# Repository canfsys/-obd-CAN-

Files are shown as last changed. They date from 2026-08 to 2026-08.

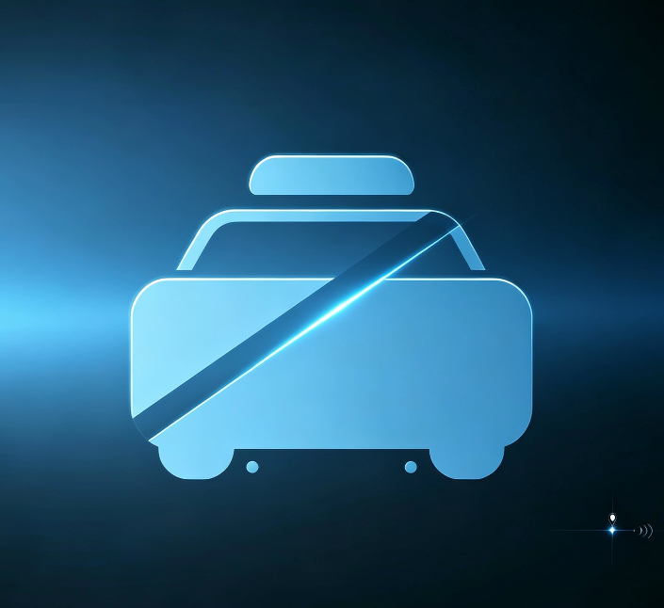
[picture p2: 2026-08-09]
miniprogram/miniprogram/images/car.png

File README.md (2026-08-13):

# OBD-CAN 车载终端 — 全链路开源项目

一套面向车联网场景的 **车载数据采集与远程监控系统**，从 PCB 硬件设计、CAN 总线数据采集、4G 上传、云端存储到微信小程序远程监控，全链路开源。

## 📦 仓库组成

| 目录 | 说明 | 核心技术 |
|---|---|---|
| [`esp32/`](esp32/README.md) | **ESP32-S3 车载终端固件** — 双通道 CAN 采集、GPS、SD 卡日志、低功耗电源管理 | C / ESP-IDF v5.3.1 / FreeRTOS |
| [`miniprogram/`](miniprogram/README.md) | **微信小程序** — 实时位置、轨迹回放、CAN 状态、历史图表、告警推送 | 微信云开发 / 云函数 |
| [`iot/`](iot/README.md) | **4G 物联网模块（银尔达 M100PG-DTU 固件版）** — 串口桥接脚本，HTTP 上报 + MQTT 下行指令 | Lua（银尔达平台） |
| [`hardware/`](hardware/README.md) | **PCB 硬件设计** — ESP32-S3 四层板（双 CAN、SD、4G、GPS、电源管理） | 嘉立创EDA专业版 / CERN-OHL-S-2.0 |

## 🏗️ 系统架构

```mermaid
graph TD
    HW["PCB 硬件设计<br/>(hardware/)"] -->|驱动| FW["ESP32-S3 车载终端固件<br/>(esp32/)"]
    FW <-->|"UART 串口协议"| IOT["4G 物联网模块<br/>(iot/) 银尔达 M100PG-DTU"]
    IOT -->|"HTTP POST (4G网络)"| CLOUD["云函数 upload<br/>(云数据库存储)"]
    CLOUD <-->|"轮询 15 秒"| MP["微信小程序<br/>(miniprogram/)"]
    CLOUD -->|"定时检测"| AC["alertChecker"]
    AC --> NT["notify"]
    NT -->|"微信订阅消息推送"| MSG["车辆告警通知"]
```

**数据链路**：车辆 CAN 数据 → ESP32 解析 → 4G 模块 HTTP 上报 → 腾讯云开发数据库 → 小程序 15 秒轮询展示 → 异常离线/非法移动 → 微信订阅消息告警。

## 🚀 快速开始

```bash
# ESP32 固件（见 esp32/README.md）
cd esp32
idf.py set-target esp32s3
idf.py build && idf.py -p COM17 flash

# 小程序：微信开发者工具导入本仓库根目录，按 miniprogram/README.md 部署
# 4G 模块：银尔达平台上传 iot/espBridge.lua，按 iot/config.md 配置通道
```

## 📄 文档索引

| 文档 | 内容 |
|---|---|
| [esp32/PROJECT_SUMMARY.md](esp32/PROJECT_SUMMARY.md) | 硬件连接、多任务架构、踩坑记录、版本记录 |
| [esp32/WAKEUP_CONFIG_SUMMARY.md](esp32/WAKEUP_CONFIG_SUMMARY.md) | 电源管理 / 唤醒配置详解 |
| [hardware/README.md](hardware/README.md) | PCB 硬件设计、引脚定义、打样/贴片说明 |
| [miniprogram/DATA_DOC.md](miniprogram/DATA_DOC.md) | 数据字段定义、数据库集合、告警链路、云函数部署 |
| [iot/config.md](iot/config.md) | 4G 平台网络通道配置 |

## ⚠️ 部署须知

- 仓库中小程序端配置已**脱敏**（`YOUR_APPID`、`YOUR_ENV_ID`、`YOUR_TEMPLATE_ID` 等占位符），部署前需替换为自己的配置，详见 `miniprogram/README.md`
- ESP32 需使用 N8R2 模组（8MB Flash + 2MB PSRAM，Quad SPI），详见 `esp32/README.md`

## 📜 许可证

本项目基于 [GPL-3.0](LICENSE) 许可证开源。

> ⚠️ **免责声明**：本项目为个人开发的参考实现，硬件涉及 CAN 总线通信与车辆数据，实际部署前请充分测试并评估安全性。

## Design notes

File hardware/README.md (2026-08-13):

# OBD-CAN 车载终端 — 硬件设计

> **硬件许可证：** [CERN-OHL-S-2.0](LICENSE)（强 copyleft，衍生硬件必须同样开源）
> **EDA 工具：** 嘉立创EDA专业版（LCEDA Pro）
> **状态：** PCB 已设计完成，尚未量产

## 📋 技术规格

| 项目 | 规格 |
|---|---|
| 主控 | ESP32-S3-WROOM-1-N8R2（8MB Flash / 2MB PSRAM，Quad SPI） |
| CAN1 | ESP32-S3 内置 TWAI 控制器 + SIT1145AQ 收发器（1MHz） |
| CAN2 | MCP2515 外置 CAN 控制器（SPI 8MHz）+ SIT1145AQ 收发器 |
| 供电 | 车载 12V 输入，含 3.8V_EN 电源控制 |
| 存储 | MicroSD 卡（SDMMC 4-bit 模式，独立电源使能） |
| 通信 | 4G 模块 UART1、GPS 模块 UART1（复用）、DS18B20 单总线 |
| 检测 | 电池电压 ADC（2:1 分压）+ 测量使能 |
| 电源管理 | Light sleep / Deep sleep，GPIO1 EXT1 高电平唤醒 |
| 板层 | 4 层板（含内层 G1/G2） |

## 📁 目录结构

```
hardware/
├── LICENSE                        # CERN-OHL-S-2.0 硬件开源许可证
├── schematic.pdf                  # 原理图（PDF 通用格式）
├── gerber/
│   ├── Gerber_PCB1.zip            # 完整 Gerber 打包（可直接打样）
│   ├── Gerber_TopLayer.GTL        # 顶层铜箔
│   ├── Gerber_BottomLayer.GBL     # 底层铜箔
│   ├── Gerber_InnerLayer1.G1      # 内层1
│   ├── Gerber_InnerLayer2.G2      # 内层2
│   ├── Gerber_*SilkscreenLayer    # 丝印层（顶/底）
│   ├── Gerber_*SolderMaskLayer    # 阻焊层（顶/底）
│   ├── Gerber_*PasteMaskLayer     # 锡膏层（顶/底）
│   ├── Gerber_BoardOutlineLayer.GKO  # 板框
│   ├── Drill_PTH/NPTH/Via.DRL     # 钻孔文件
│   ├── FlyingProbeTesting.json    # 飞针测试文件
│   └── PCB下单必读.txt
├── bom/
│   ├── BOM_Board1_PCB1.xlsx       # 物料清单（元器件/数量/封装）
│   └── PickAndPlace_PCB1.xlsx     # 贴片坐标文件（SMT 使用）
├── images/
│   ├── 3D_PCB1_TopLayer.png       # PCB 3D 顶面预览
│   └── 3D_PCB1_BottomLayer.png    # PCB 3D 底面预览
└── source/
    └── OBD_CAN_Module_v2.0.eprj2  # 嘉立创EDA专业版工程源文件（可二次编辑）
```

## 🔌 引脚分配

| 功能 | 组件 | GPIO | 说明 |
|---|---|:----:|---|
| UART0_TX / UART0_RX | 调试串口 | 43 / 44 | 控制台输出 (115200) |
| USB D- / D+ | 内置 | 19 / 20 | USB Serial/JTAG 烧录 |
| SPI_MISO / MOSI / SCK | spi_bus | 16 / 17 / 18 | 共享 SPI2 总线 |
| SIT1145-1_CS | sit1145 (CAN1) | 5 | TWAI 路收发器 (1MHz, mode1) |
| SIT1145-2_CS | sit1145 (CAN2) | 6 | MCP2515 路收发器 (1MHz, mode1) |
| MCP2515_CS | mcp2515 | 7 | 外置 CAN 控制器 (8MHz, mode0) |
| MCP2515_INT | mcp2515 | 8 | 中断引脚 (下降沿) |
| TWAI_TX / TWAI_RX | twai | 10 / 9 | ESP32-S3 内置 CAN |
| SD_CLK/CMD/D0~D3 | sd_card | 14/15/2/4/12/13 | SDMMC 4-bit |
| SD_PWR_EN | sd_card | 38 | SD 卡电源使能 |
| 4G_TX / 4G_RX | modem_4g | 41 / 42 | 4G 模块 UART1 |
| 4G_RESET | modem_4g | 47 | 4G 模块复位 |
| 3.8V_EN | 电源控制 | 21 | 4G 模块/外部电源使能 |
| BAT_ADC | adc | 11 | 电池电压检测 (ADC2_CH0) |
| BAT_MEAS_EN | adc | 39 | ADC 通道开关 |
| DS18B20 | ds18b20 | 40 | 单总线温度传感器 |
| WAKE_IN | 外部中断 | 1 | GPIO1 EXT1 高电平唤醒 |

## 🛠️ 使用说明

### 打样 PCB
1. 将 `gerber/Gerber_PCB1.zip` 直接上传至嘉立创下单助手 / 制板厂
2. 按 `PCB下单必读.txt` 中的要求下单

### 贴片生产（SMT）
1. 打开 `bom/BOM_Board1_PCB1.xlsx` 核对元器件
2. 使用 `bom/PickAndPlace_PCB1.xlsx` 贴片坐标文件
3. 配合飞针测试文件 `FlyingProbeTesting.json` 验证

### 二次开发（修改电路）
1. 用嘉立创EDA专业版打开 `source/OBD_CAN_Module_v2.0.eprj2` 工程文件
2. 修改后导出新的 Gerber / BOM / 原理图 PDF 更新到对应目录

## 📜 许可证

硬件设计基于 [CERN-OHL-S-2.0](LICENSE) 开源。固件与软件部分见仓库根目录 GPL-3.0 许可证。

> ⚠️ **免责声明**：本设计为个人开发参考，涉及车辆 CAN 总线与电气系统，实际使用前请充分测试并评估安全风险。

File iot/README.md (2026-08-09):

# IoT 物联网模块 — 4G 通信桥

> **模块型号：银尔达 M100PG-DTU 固件版**

本目录是车载终端 **4G 通信模块**（银尔达 M100PG-DTU）的桥接代码（银尔达物联网平台 Lua 任务），负责将 ESP32 采集到的车辆数据通过移动网络上报到云端，并接收云端下行的指令。

## 系统位置

```
┌──────────────┐   UART   ┌───────────────────────┐   HTTP/MQTT   ┌─────────────────┐
│   ESP32 固件  │◀────────▶│ 4G 模块 (espBridge.lua) │──────────────▶│ 云函数 upload   │
│ (esp32/)     │  串口协议 │ (本目录 iot/)           │   4G 网络      │ (miniprogram/)  │
└──────────────┘          └───────────────────────┘               └────────┬────────┘
                                                                           │
                                                                   ┌───────▼────────┐
                                                                   │ 微信小程序前端   │
                                                                   └────────────────┘
```

## 功能

- **UART 通信**：与 ESP32 交互，处理查询命令 `NET?` / `IMEI?` / `TIME?` / `GPS?` / `STATUS?`，返回 `KEY=VALUE` 格式数据
- **HTTP 上报**：将车辆实时状态 POST 到云端云函数 `/upload`（腾讯云开发环境）
- **MQTT 通道**：订阅 `carXXXdown` / 发布 `carXXXup` 主题，支持远程指令下行
- **GPS 透传**：模块自带 GPS 引擎，可向 ESP32 提供定位数据
- **网络透传**：4G 网络收到的数据透明转发给 ESP32

## 文件说明

| 文件 | 说明 |
|---|---|
| `espBridge.lua` | 银尔达平台 Lua 任务脚本（核心桥接逻辑） |
| `config.md` | 银尔达平台「网络通道」配置说明（HTTP/MQTT） |

## 使用前提

1. 一台 **银尔达 M100PG-DTU 固件版** 4G 模组（或兼容银尔达 Lua 平台的同系列模组）
2. 按 `config.md` 在平台控制台配置好网络通道
3. 将 `espBridge.lua` 上传为平台任务并启用

> 串口命令协议与 ESP32 侧 `gps_poller` / `modem_4g` 组件对应，见 `esp32/PROJECT_SUMMARY.md`。

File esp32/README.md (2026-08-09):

# ESP32-S3 车载终端 — 多通道 CAN 数据采集

基于 **ESP32-S3-WROOM-1-N8R2** 的多通道 CAN 总线数据采集与存储终端，面向车载环境设计。支持内置 TWAI 控制器 + 外置 MCP2515 双通道 CAN 采集、SD 卡 CSV 日志、GPS 定时轮询、电池电压监测，以及完整的 light/deep sleep 低功耗电源管理。

## 功能特性

- 🚗 **双通道 CAN 采集**
  - CAN1: ESP32-S3 内置 TWAI 控制器 (125kbps) + SIT1145 收发器
  - CAN2: MCP2515 外置控制器 (SPI) + SIT1145 收发器
- 📦 **PSRAM 双缓冲区** — 4×64KB 缓冲区，CAN 帧满后通过共享信号量异步落盘，不丢帧
- 💾 **SD 卡 CSV 日志** — 按组件自动建目录、文件自动编号 (can_0001.csv) 并追加写入
- 🔋 **三级电源管理** — NORMAL → STANDBY → SLEEP (light sleep 3 次定时器唤醒后转 deep sleep)
- 🛰️ **GPS 定时轮询** — 进入 sleep 前设置 3 分钟定时器，唤醒后通过 UART1 查询 GPS 状态
- 📡 **4G 模块接口** — UART1 私有协议 + 复位控制 (开发中)
- 🌡️ **温度/电压监测** — DS18B20 单总线温度 + ADC 电池电压检测
- ⚡ **多核任务架构** — CAN 接收任务绑核最高优先级，SD 写入任务最低优先级防阻塞
- 🔋 **低功耗唤醒** — GPIO1 EXT1 高电平唤醒 + RTC 定时器自主唤醒

## 硬件要求

| 项目 | 规格 |
|---|---|
| 主控 | ESP32-S3-WROOM-1-N8R2 (8MB Flash / 2MB PSRAM) |
| CAN1 | ESP TWAI (GPIO9/10) + SIT1145AQ 收发器 (SPI 配置) |
| CAN2 | MCP2515 (SPI) + SIT1145AQ 收发器 |
| 存储 | MicroSD 卡 (SDMMC 4-bit 模式) |
| 外设 | 4G 模块 (UART1)、GPS 模块 (UART1)、DS18B20、电池 |

## 引脚分配

| 功能 | GPIO | 说明 |
|---|:----:|---|
| UART0_TX / UART0_RX | 43 / 44 | 调试串口 (115200) |
| USB D- / D+ | 19 / 20 | USB Serial/JTAG 烧录 |
| SPI_MISO / MOSI / SCK | 16 / 17 / 18 | 共享 SPI2 总线 |
| SIT1145-1_CS | 5 | CAN1 收发器配置 (1MHz, mode1) |
| SIT1145-2_CS | 6 | CAN2 收发器配置 (1MHz, mode1) |
| MCP2515_CS | 7 | 外置 CAN 控制器 (8MHz, mode0) |
| MCP2515_INT | 8 | 中断 (下降沿) |
| TWAI_TX / TWAI_RX | 10 / 9 | 内置 CAN 控制器 |
| SD_CLK/CMD/D0~D3 | 14/15/2/4/12/13 | SDMMC 4-bit |
| SD_PWR_EN | 38 | SD 卡电源使能 |
| 4G_TX / 4G_RX | 41 / 42 | 4G 模块 UART1 |
| 4G_RESET | 47 | 4G 模块复位 |
| 3.8V_EN | 21 | 4G 模块/外部电源使能 |
| BAT_ADC / BAT_MEAS_EN | 11 / 39 | 电池电压检测 |
| DS18B20 | 40 | 温度传感器 |
| WAKE_IN | 1 | GPIO1 EXT1 高电平唤醒 |

## 软件要求

- **ESP-IDF v5.3.1**（其他 v5.x 版本理论上兼容）
- 目标芯片: `esp32s3`
- 需启用 PSRAM（Quad SPI 模式，`CONFIG_SPIRAM_MODE_QUAD`）

## 构建与烧录

```bash
# 设置 ESP-IDF 环境后
idf.py set-target esp32s3
idf.py menuconfig    # 按需调整 (见下方注意事项)
idf.py build
idf.py -p COM17 flash   # 替换为你的串口号
idf.py monitor          # 或使用串口助手连接 UART0 (115200-8N1)
```

### ⚠️ 构建注意事项

1. **PSRAM 必须为 Quad SPI 模式**（N8R2 模组），否则启动报错
2. **Flash 大小需设为 8MB**（`idf.py menuconfig` → Serial flasher config）
3. 调试串口为 **UART0 (GPIO43/44)**，USB Serial/JTAG 仅用于烧录

## 项目结构

```
├── CMakeLists.txt              # EXTRA_COMPONENT_DIRS=components
├── main/
│   └── main.c                  # 主入口: 唤醒判断 + 初始化 + 4 任务
└── components/                 # 自定义组件 (14 个)
    ├── board_config/           # 板级引脚定义
    ├── spi_bus/                # SPI2_HOST 共享总线 + 设备名映射
    ├── sit1145/                # SIT1145AQ CAN 收发器驱动
    ├── mcp2515/                # MCP2515 CAN 控制器驱动 (含重试)
    ├── twai/                   # ESP TWAI CAN 驱动封装 (Alert 中断)
    ├── sd_card/                # SD 卡 FATFS 挂载/读写
    ├── sd_logger/              # SD 卡 CSV 日志写入器
    ├── can_buffer/             # PSRAM 双缓冲区管理器
    ├── can_parser/             # CAN 数据帧解析器
    ├── modem_4g/               # 4G 模块 (UART + AT 命令)
    ├── ds18b20/                # 单总线温度传感器
    ├── adc/                    # 电池电压检测
    ├── power_manager/          # 电源管理 (三种模式 + GPIO 唤醒)
    └── gps_poller/             # GPS 轮询器
```

## 多任务架构

| 任务 | 绑核 | 优先级 | 触发方式 | 功能 |
|---|:----:|:---:|---|---|
| `mcp2515_task` | Core0 | 24 | GPIO 下降沿 ISR | SPI 读 MCP2515 → 缓冲区 + 解析 |
| `twai_task` | Core1 | 24 | TWAI Alert(RXI) 中断 | 读 TWAI RX FIFO → 缓冲区 + 解析 |
| `sd_write_task` | Core1 | 1 | 共享信号量 | 缓冲区满 → 写 SD 卡 CSV |
| `sensor_task` | Core1 | 5 | `vTaskDelay(1000)` | 温度/电压打印 + 电源空闲检测 |

## 相关文档

- [PROJECT_SUMMARY.md](PROJECT_SUMMARY.md) — 硬件连接、架构、踩坑记录、版本记录
- [WAKEUP_CONFIG_SUMMARY.md](WAKEUP_CONFIG_SUMMARY.md) — 电源管理 / 唤醒配置详细说明

## 许可证

本项目基于 [GPL-3.0](LICENSE) 许可证开源。

> ⚠️ **免责声明**: 本项目为个人开发的参考实现，硬件涉及 CAN 总线通信，实际部署前请充分测试并评估安全性。

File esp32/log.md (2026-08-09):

GPIO1唤醒
[06:39:26.528] I (71669) MAIN: ===== 空闲超时, 进入待机 =====
[06:39:26.528] I (71669) TWAI: 卸载 TWAI 驱动
[06:39:26.528] I (71669) SD_CARD: SD 卡已卸载
[06:39:26.528] I (71679) POWER_MGR: ===== light sleep =====
[06:39:26.528] I (71679) SPI_BUS: SIT1145-1 TX(16bit): 98 03 | (无RX)
[06:39:26.528] I (71689) POWER_MGR: SIT1145-1 写 0x4C = 0x03
[06:39:26.528] I (71689) SPI_BUS: SIT1145-1 TX(16bit): 40 01 | (无RX)
[06:39:26.528] I (71699) POWER_MGR: SIT1145-1 写 0x20 = 0x01
[06:39:26.528] I (71709) SPI_BUS: SIT1145-1 TX(16bit): 08 00 | (无RX)
[06:39:26.528] I (71709) POWER_MGR: SIT1145-1 写 0x04 = 0x00
[06:39:26.528] I (71719) SPI_BUS: SIT1145-1 TX(16bit): 46 01 | (无RX)
[06:39:26.528] I (71719) POWER_MGR: SIT1145-1 写 0x23 = 0x01
[06:39:26.528] I (71729) SPI_BUS: SIT1145-1 TX(16bit): C2 FF | (无RX)
[06:39:26.528] I (71729) POWER_MGR: SIT1145-1 写 0x61 = 0xFF
[06:39:26.528] I (71739) SPI_BUS: SIT1145-1 TX(16bit): C3 00 | RX: C3 00 
[06:39:26.528] I (71739) POWER_MGR:   回读 0x61=0x00
[06:39:26.528] I (71749) SPI_BUS: SIT1145-1 TX(16bit): C6 FF | (无RX)
[06:39:26.528] I (71749) POWER_MGR: SIT1145-1 写 0x63 = 0xFF
[06:39:26.528] I (71759) SPI_BUS: SIT1145-1 TX(16bit): C8 FF | (无RX)
[06:39:26.528] I (71769) POWER_MGR: SIT1145-1 写 0x64 = 0xFF
[06:39:26.528] I (71769) SPI_BUS: SIT1145-1 TX(16bit): C9 00 | RX: C9 00 
[06:39:26.528] I (71779) POWER_MGR:   回读 0x64=0x00
[06:39:26.528] I (71779) SPI_BUS: SIT1145-1 TX(16bit): 02 01 | (无RX)
[06:39:26.528] I (71789) POWER_MGR: SIT1145-1 写 0x01 = 0x01
[06:39:26.528] I (71789) SPI_BUS: SIT1145-2 TX(16bit): 98 03 | (无RX)
[06:39:26.528] I (71799) POWER_MGR: SIT1145-2 写 0x4C = 0x03
[06:39:26.528] I (71799) SPI_BUS: SIT1145-2 TX(16bit): 40 01 | (无RX)
[06:39:26.528] I (71809) POWER_MGR: SIT1145-2 写 0x20 = 0x01
[06:39:26.528] I (71809) SPI_BUS: SIT1145-2 TX(16bit): 08 00 | (无RX)
[06:39:26.528] I (71819) POWER_MGR: SIT1145-2 写 0x04 = 0x00
[06:39:26.528] I (71829) SPI_BUS: SIT1145-2 TX(16bit): 46 01 | (无RX)
[06:39:26.528] I (71829) POWER_MGR: SIT1145-2 写 0x23 = 0x01
[06:39:26.528] I (71839) SPI_BUS: SIT1145-2 TX(16bit): C2 FF | (无RX)
[06:39:26.528] I (71839) POWER_MGR: SIT1145-2 写 0x61 = 0xFF
[06:39:26.528] I (71849) SPI_BUS: SIT1145-2 TX(16bit): C3 00 | RX: C3 00 
[06:39:26.528] I (71849) POWER_MG
[06:39:26.725] R:   回读 0x61=0x00
[06:39:26.725] I (71859) SPI_BUS: SIT1145-2 TX(16bit): C6 FF | (无RX)
[06:39:26.725] I (71859) POWER_MGR: SIT1145-2 写 0x63 = 0xFF
[06:39:26.725] I (71869) SPI_BUS: SIT1145-2 TX(16bit): C8 FF | (无RX)
[06:39:26.725] I (71879) POWER_MGR: SIT1145-2 写 0x64 = 0xFF
[06:39:26.725] I (71879) SPI_BUS: SIT1145-2 TX(16bit): C9 00 | RX: C9 00 
[06:39:26.725] I (71889) POWER_MGR:   回读 0x64=0x00
[06:39:26.725] I (71889) SPI_BUS: SIT1145-2 TX(16bit): 02 01 | (无RX)
[06:39:26.725] I (71899) POWER_MGR: SIT1145-2 写 0x01 = 0x01
[06:39:26.725] I (71899) POWER_MGR: MCP2515: 清除 WAKIF
[06:39:26.725] I (71909) SPI_BUS: MCP2515 TX(32bit): 05 2C 40 00 | (无RX)
[06:39:26.725] I (71909) POWER_MGR: MCP2515: 使能 WAKIE
[06:39:26.725] I (71919) SPI_BUS: MCP2515 TX(32bit): 05 2B 40 40 | (无RX)
[06:39:26.725] I (71919) POWER_MGR: MCP2515: 休眠
[06:39:26.725] I (71929) SPI_BUS: MCP2515 TX(32bit): 05 0F E0 20 | (无RX)
[06:39:26.725] I (71929) POWER_MGR: SPI/CAN 休眠完成 (已清除初始化标
[06:39:31.231] 志)
[06:39:31.231] rtc_gpio_is_valid_gpio(GPIO1) = 1
[06:39:31.231] I (71949) POWER_MGR: 进入 light sleep (3min GPS, GPIO1/42 唤醒)
[06:39:31.231] I (71949) POWER_MGR: 唤醒 原因=3(EXT1(GPIO1))
[06:39:31.231] I (71969) MAIN: ===== 唤醒后重新初始化外设 =====
[06:39:31.231] I (71969) MAIN: [1/5] 重新添加 SPI 设备...
[06:39:31.231] I (71969) SPI_BUS: 删除 SPI 设备 (handle=0x0x3fca6e00)
[06:39:31.231] I (71979) gpio: GPIO[5]| InputEn: 0| OutputEn: 0| OpenDrain: 0| Pullup: 1| Pulldown: 0| Intr:0 
[06:39:31.231] I (71989) SPI_BUS: 删除 SPI 设备 (handle=0x0x3fca6fb0)
[06:39:31.231] I (71989) gpio: GPIO[6]| InputEn: 0| OutputEn: 0| OpenDrain: 0| Pullup: 1| Pulldown: 0| Intr:0 
[06:39:31.231] I (71999) SPI_BUS: 删除 SPI 设备 (handle=0x0x3fca7160)
[06:39:31.231] I (72009) gpio: GPIO[7]| InputEn: 0| OutputEn: 0| OpenDrain: 0| Pullup: 1| Pulldown: 0| Intr:0 
[06:39:31.231] I (72019) SPI_BUS: 设备 (CS=5) 添加成功, 速度=1000000Hz, mode=1
[06:39:31.231] I (72019) SPI_BUS: 设备 (CS=6) 添加成功, 速度=1000000Hz, mode=1
[06:39:31.231] I (72029) SPI_BUS: 设备 (CS=7) 添加成功, 速度=8000000Hz, mode=0
[06:39:31.231] I (72039) MAIN: [2/5] 初始化 SIT1145...
[06:39:31.231] I (72039) SIT1145: 初始化 SIT1145-1 (CS=GPIO5)
[06:39:31.231] I (72049) SPI_BUS: SIT1145-1 TX(16bit): 02 07 | (无RX)
[06:39:31.231] I (72059) SPI_BUS: SIT1145-1 TX(16bit): 56 03 | (无RX)
[06:39:31.231] I (72059) SIT1145: SIT1145-1 写入: reg[0x26]=0x02
[06:39:31.231] I (72069) SPI_BUS: SIT1145-1 TX(16bit): 4C 02 | (无RX)
[06:39:31.231] I (72069) SIT1145: SIT1145-1 写入: reg[0x20]=0x32
[06:39:31.231] I (72079) SPI_BUS: SIT1145-1 TX(16bit): 40 32 | (无RX)
[06:39:31.231] I (72079) SPI_BUS: SIT1145-1 TX(16bit): 4D 00 | RX: 4D 02 
[06:39:31.231] I (72089) SPI_BUS: SIT1145-1 TX(16bit): 41 00 | RX: 41 32 
[06:39:31.231] I (72099) SPI_BUS: SIT1145-1 TX(16bit): 45 00 | RX: 45 A0 
[06:39:31.231] I (72099) SIT1145: SIT1145-1 读回验证: reg[0x26]=0x02, reg[0x20]=0x32, reg[0x22]=0xA0
[06:39:31.231] I (72109) SIT1145: SIT1145-1 验证通过 ✓
[06:39:31.231] I (72119) SIT1145: SIT1145-1 初始化完成 (retry=0)
[06:39:31.231] I (72119) SIT1145: 初始化 SIT1145-2 (CS=GPIO6)
[06:39:31.231] I (72129) SPI_BUS: SIT1145-2 TX(16bit): 02 07 | (无RX)
[06:39:31.231] I (72129) SPI_BUS: SIT1145-2 TX(16bit): 56 03 | (无RX)
[06:39:31.231] I 
[06:39:31.429] (72139) SIT1145: SIT1145-2 写入: reg[0x26]=0x05
[06:39:31.429] I (72139) SPI_BUS: SIT1145-2 TX(16bit): 4C 05 | (无RX)
[06:39:31.429] I (72149) SIT1145: SIT1145-2 写入: reg[0x20]=0x32
[06:39:31.429] I (72159) SPI_BUS: SIT1145-2 TX(16bit): 40 32 | (无RX)
[06:39:31.429] I (72159) SPI_BUS: SIT1145-2 TX(16bit): 4D 00 | RX: 4D 05 
[06:39:31.429] I (72169) SPI_BUS: SIT1145-2 TX(16bit): 41 00 | RX: 41 32 
[06:39:31.429] I (72169) SPI_BUS: SIT1145-2 TX(16bit): 45 00 | RX: 45 A8 
[06:39:31.429] I (72179) SIT1145: SIT1145-2 读回验证: reg[0x26]=0x05, reg[0x20]=0x32, reg[0x22]=0xA8
[06:39:31.429] I (72189) SIT1145: SIT1145-2 验证通过 ✓
[06:39:31.429] I (72189) SIT1145: SIT1145-2 初始化完成 (retry=0)
[06:39:31.429] I (72199) MAIN: [3/5] 初始化 MCP2515...
[06:39:31.429] I (72209) MCP2515: MCP2515 初始化开始 (INT=GPIO8)
[06:39:31.429] I (72209) MCP2515: GPIO8 下降沿中断已安装
[06:39:31.429] I (72219) SPI_BUS: MCP2515 TX(8bit): C0 | (无RX)
[06:39:31.429] I (72229) MCP2515: 复位完成
[06:39:31.429] I (72229) SPI_BUS: MCP2515 TX(24bit): 02 2A 00 | (无RX)
[06:39:31.429] I (72229) SPI_BUS: MCP2515 TX(24bit): 02 29 90 | (无RX)
[06:39:31.429] I (72239) SPI_BUS: MCP2515 TX(24bit): 02 28 02 | (无RX)
[06:39:31.429] I (72239) MCP2515: 波特率配置完成 (CNF1=0x00, CNF2=0x90, CNF3=0x02)
[06:39:31.429] I (72249) SPI_BUS: MCP2515 TX(24bit): 02 60 60 | (无RX)
[06:39:31.429] I (72259) SPI_BUS: MCP2515 TX(24bit): 02 70 60 | (无RX)
[06:39:31.429] I (72259) MCP2515: 过滤器已关闭 (接收所有帧)
[06:39:31.429] I (72269) SPI_BUS: MCP2515 TX(24bit): 02 0C 00 | (无RX)
[06:39:31.429] I (72269) MCP2515: RXnBF 引脚中断已关闭
[06:39:31.429] I (72279) SPI_BUS: MCP2515 TX(24bit): 02 2B 03 | (无RX)
[06:39:31.429] I (72289) MCP2515: INT 引脚中断已开启 (RXB0IE + RXB1IE)
[06:39:31.429] I (72289) SPI_BUS: MCP2515 TX(24bit): 02 2C 00 | (无RX)
[06:39:31.429] I (72299) MCP2515: 中断标志已清除
[06:39:31.429] I (72299) SPI_BUS: MCP2515 TX(24bit): 02 0F 00 | (无RX)
[06:39:31.429] I (72309) SPI_BUS: MCP2515 TX(24bit): 03 0E 00 | RX: FF FF FF 
[06:39:31.429] I (72319) MCP2515: MCP2515 验证 (retry=0, CANSTAT=0xFF, OPMOD=7 异常)
[06:39:31.429] W (72319) MCP2515: OPMOD 异常, 复位重试...
[06:39:31.429] I (72329) SPI_BUS: MCP2515 TX(8bit): C0 | (无RX)
[06:39:31.429] I (72339) SPI_BUS: MCP2515 TX(24bit): 02 2A 00 | (无RX)
[06:39:31.429] I (72339) SPI_BUS: MCP2515 TX(24bit): 02 29 90 | (无RX)
[06:39:31.635] 
[06:39:31.635] I (72349) SPI_BUS: MCP2515 TX(24bit): 02 28 02 | (无RX)
[06:39:31.635] I (72349) SPI_BUS: MCP2515 TX(24bit): 02 60 60 | (无RX)
[06:39:31.635] I (72359) SPI_BUS: MCP2515 TX(24bit): 02 70 60 | (无RX)
[06:39:31.635] I (72359) SPI_BUS: MCP2515 TX(24bit): 02 0C 00 | (无RX)
[06:39:31.635] I (72369) SPI_BUS: MCP2515 TX(24bit): 02 2B 03 | (无RX)
[06:39:31.635] I (72379) SPI_BUS: MCP2515 TX(24bit): 02 2C 00 | (无RX)
[06:39:31.635] I (72379) SPI_BUS: MCP2515 TX(24bit): 02 0F 00 | (无RX)
[06:39:31.635] I (72389) MCP2515: 重试 1: 重新配置 CANCTRL=0x00
[06:39:31.635] I (72389) SPI_BUS: MCP2515 TX(24bit): 03 0E 00 | RX: FF FF 00 
[06:39:31.635] I (72399) MCP2515: MCP2515 验证 (retry=1, CANSTAT=0x00, OPMOD=0 Normal ✓)
[06:39:31.635] I (72409) MAIN: [4/5] 挂载 SD 卡...
[06:39:31.635] I (72409) gpio: GPIO[14]| InputEn: 0| OutputEn: 0| OpenDrain: 0| Pullup: 1| Pulldown: 0| Intr:0 
[06:39:31.635] I (72419) gpio: GPIO[15]| InputEn: 0| OutputEn: 0| OpenDrain: 0| Pullup: 1| Pulldown: 0| Intr:0 
[06:39:31.635] I (72429) gpio: GPIO[2]| InputEn: 0| OutputEn: 0| OpenDrain: 0| Pullup: 1| Pulldown: 0| Intr:0 
[06:39:31.635] I (72439) gpio: GPIO[4]| InputEn: 0| OutputEn: 0| OpenDrain: 0| Pullup: 1| Pulldown: 0| Intr:0 
[06:39:31.635] I (72449) gpio: GPIO[12]| InputEn: 0| OutputEn: 0| OpenDrain: 0| Pullup: 1| Pulldown: 0| Intr:0 
[06:39:31.635] I (72459) gpio: GPIO[13]| InputEn: 0| OutputEn: 0| OpenDrain: 0| Pullup: 1| Pulldown: 0| Intr:0 
[06:39:31.858] I (72579) gpio: GPIO[14]| InputEn: 0| OutputEn: 0| OpenDrain: 0| Pullup: 1| Pulldown: 0| Intr:0 
[06:39:31.858] I (72579) gpio: GPIO[15]| InputEn: 0| OutputEn: 0| OpenDrain: 0| Pullup: 1| Pulldown: 0| Intr:0 
[06:39:31.858] I (72589) gpio: GPIO[2]| InputEn: 0| OutputEn: 0| OpenDrain: 0| Pullup: 1| Pulldown: 0| Intr:0 
[06:39:31.858] I (72599) gpio: GPIO[4]| InputEn: 0| OutputEn: 0| OpenDrain: 0| Pullup: 1| Pulldown: 0| Intr:0 
[06:39:31.858] I (72609) gpio: GPIO[12]| InputEn: 0| OutputEn: 0| OpenDrain: 0| Pullup: 1| Pulldown: 0| Intr:0 
[06:39:31.858] I (72619) gpio: GPIO[13]| InputEn: 0| OutputEn: 1| OpenDrain: 0| Pullup: 0| Pulldown: 0| Intr:0 
[06:39:31.858] I (72659) gpio: GPIO[13]| InputEn: 0| OutputEn: 0| OpenDrain: 0| Pullup: 1| Pulldown: 0| Intr:0 
[06:39:31.858] Name: SD
[06:39:31.858] Type: SDHC/SDXC
[06:39:31.858] Speed: 20.00 MHz (limit: 20.00 MHz)
[06:39:31.858] Size: 29818MB
[06:39:31.858] CSD: ver=2, sector_size=512, capacity=61067264 read_bl_len=9
[06:39:31.858] SSR: bus_width=4
[06:39:31.858] I (72679) SD_CARD: SD 卡初始化成功
[06:39:33.532] I (74249) SD_LOG: sit1145: 新文件 /sdcard/sit1145/can_0322.csv 已创建 (编号=322)
[06:39:35.047] I (75769) SD_LOG: mcp2515: 新文件 /sdcard/mcp2515/can_0321.csv 已创建 (编号=321)
[06:39:35.047] I (75769) MAIN: [5/5] 注册句柄...
[06:39:35.047] I (75769) MCP2515: 已注册任务 (handle=0x0x3fca8768) 接收 MCP2515 中断通知
[06:39:35.047] I (75779) MAIN: ===== 外设重新初始化完成 =====
[06:39:35.362] Guru Meditation Error: Core  1 panic'ed (Interrupt wdt timeout on CPU1). 
[06:39:35.362] 
[06:39:35.362] Core  1 register dump:
[06:39:35.362] PC      : 0x4037a0fe  PS      : 0x00060834  A0      : 0x8037e55c  A1      : 0x3fca9220  
[06:39:35.362] A2      : 0x3c061330  A3      : 0xb33fffff  A4      : 0x0000abab  A5      : 0x00060a23  
[06:39:35.362] A6      : 0x00001b8a  A7      : 0x3fc9a740  A8      : 0x00000000  A9      : 0x00060823  
[06:39:35.362] A10     : 0x3c061330  A11     : 0x3fc9808c  A12     : 0x00000000  A13     : 0x4cc00001  
[06:39:35.362] A14     : 0x3c046b3f  A15     : 0x0000abab  SAR     : 0x0000000a  EXCCAUSE: 0x00000006  
[06:39:35.362] EXCVADDR: 0x00000000  LBEG    : 0x40056f5c  LEND    : 0x40056f72  LCOUNT  : 0x00000000  
[06:39:35.362] 

GPIO42唤醒
[06:38:05.131] I (65575) MAIN: ===== 空闲超时, 进入待机 =====
[06:38:05.131] I (65575) TWAI: 卸载 TWAI 驱动
[06:38:05.131] I (65575) SD_CARD: SD 卡已卸载
[06:38:05.131] I (65585) POWER_MGR: ===== light sleep =====
[06:38:05.131] I (65585) SPI_BUS: SIT1145-1 TX(16bit): 98 03 | (无RX)
[06:38:05.131] I (65595) POWER_MGR: SIT1145-1 写 0x4C = 0x03
[06:38:05.131] I (65595) SPI_BUS: SIT1145-1 TX(16bit): 40 01 | (无RX)
[06:38:05.131] I (65605) POWER_MGR: SIT1145-1 写 0x20 = 0x01
[06:38:05.131] I (65615) SPI_BUS: SIT1145-1 TX(16bit): 08 00 | (无RX)
[06:38:05.131] I (65615) POWER_MGR: SIT1145-1 写 0x04 = 0x00
[06:38:05.131] I (65625) SPI_BUS: SIT1145-1 TX(16bit): 46 01 | (无RX)
[06:38:05.131] I (65625) POWER_MGR: SIT1145-1 写 0x23 = 0x01
[06:38:05.131] I (65635) SPI_BUS: SIT1145-1 TX(16bit): C2 FF | (无RX)
[06:38:05.131] I (65635) POWER_MGR: SIT1145-1 写 0x61 = 0xFF
[06:38:05.131] I (65645) SPI_BUS: SIT1145-1 TX(16bit): C3 00 | RX: C3 00 
[06:38:05.131] I (65645) POWER_MGR:   回读 0x61=0x00
[06:38:05.131] I (65655) SPI_BUS: SIT1145-1 TX(16bit): C6 FF | (无RX)
[06:38:05.131] I (65655) POWER_MGR: SIT1145-1 写 0x63 = 0xFF
[06:38:05.131] I (65665) SPI_BUS: SIT1145-1 TX(16bit): C8 FF | (无RX)
[06:38:05.131] I (65675) POWER_MGR: SIT1145-1 写 0x64 = 0xFF
[06:38:05.131] I (65675) SPI_BUS: SIT1145-1 TX(16bit): C9 00 | RX: C9 00 
[06:38:05.131] I (65685) POWER_MGR:   回读 0x64=0x00
[06:38:05.131] I (65685) SPI_BUS: SIT1145-1 TX(16bit): 02 01 | (无RX)
[06:38:05.131] I (65695) POWER_MGR: SIT1145-1 写 0x01 = 0x01
[06:38:05.131] I (65695) SPI_BUS: SIT1145-2 TX(16bit): 98 03 | (无RX)
[06:38:05.131] I (65705) POWER_MGR: SIT1145-2 写 0x4C = 0x03
[06:38:05.131] I (65705) SPI_BUS: SIT1145-2 TX(16bit): 40 01 | (无RX)
[06:38:05.131] I (65715) POWER_MGR: SIT1145-2 写 0x20 = 0x01
[06:38:05.131] I (65715) SPI_BUS: SIT1145-2 TX(16bit): 08 00 | (无RX)
[06:38:05.131] I (65725) POWER_MGR: SIT1145-2 写 0x04 = 0x00
[06:38:05.131] I (65735) SPI_BUS: SIT1145-2 TX(16bit): 46 01 | (无RX)
[06:38:05.131] I (65735) POWER_MGR: SIT1145-2 写 0x23 = 0x01
[06:38:05.131] I (65745) SPI_BUS: SIT1145-2 TX(16bit): C2 FF | (无RX)
[06:38:05.131] I (65745) POWER_MGR: SIT1145-2 写 0x61 = 0xFF
[06:38:05.131] I (65755) SPI_BUS: SIT1145-2 TX(16bit): C3 00 | RX: C3 00 
[06:38:05.131] I (65755) POWER_MGR:   回读 0x61=0x00
[06:38:05.131] I (65765) SPI_BUS: SIT1145-2 TX(16bit): C6 FF | (无RX)
[06:38:05.131] I (65765) POWER_MGR: SIT1145-2 写 0x63 = 0xFF
[06:38:05.131] I (65775) SPI_BUS: SIT1145-2 TX
[06:38:05.346] (16bit): C8 FF | (无RX)
[06:38:05.346] I (65785) POWER_MGR: SIT1145-2 写 0x64 = 0xFF
[06:38:05.346] I (65785) SPI_BUS: SIT1145-2 TX(16bit): C9 00 | RX: C9 00 
[06:38:05.346] I (65795) POWER_MGR:   回读 0x64=0x00
[06:38:05.346] I (65795) SPI_BUS: SIT1145-2 TX(16bit): 02 01 | (无RX)
[06:38:05.346] I (65805) POWER_MGR: SIT1145-2 写 0x01 = 0x01
[06:38:05.346] I (65805) POWER_MGR: MCP2515: 清除 WAKIF
[06:38:05.346] I (65815) SPI_BUS: MCP2515 TX(32bit): 05 2C 40 00 | (无RX)
[06:38:05.346] I (65815) POWER_MGR: MCP2515: 使能 WAKIE
[06:38:05.346] I (65825) SPI_BUS: MCP2515 TX(32bit): 05 2B 40 40 | (无RX)
[06:38:05.346] I (65825) POWER_MGR: MCP2515: 休眠
[06:38:05.346] I (65835) SPI_BUS: MCP2515 TX(32bit): 05 0F E0 20 | (无RX)
[06:38:05.346] I (65835) POWER_MGR: SPI/CAN 休眠完成 (已清除初始化标
[06:38:10.770] 志)
[06:38:10.770] rtc_gpio_is_valid_gpio(GPIO1) = 1
[06:38:10.770] I (65855) POWER_MGR: 进入 light sleep (3min GPS, GPIO1/42 唤醒)
[06:38:10.770] I (65855) POWER_MGR: 唤醒 原因=7(IO MUX GPIO)
[06:38:10.770] I (65875) MAIN: ===== 唤醒后重新初始化外设 =====
[06:38:10.770] I (65875) MAIN: [1/5] 重新添加 SPI 设备...
[06:38:10.770] I (65875) SPI_BUS: 删除 SPI 设备 (handle=0x0x3fca6e00)
[06:38:10.770] I (65885) gpio: GPIO[5]| InputEn: 0| OutputEn: 0| OpenDrain: 0| Pullup: 1| Pulldown: 0| Intr:0 
[06:38:10.770] I (65895) SPI_BUS: 删除 SPI 设备 (handle=0x0x3fca6fb0)
[06:38:10.770] I (65895) gpio: GPIO[6]| InputEn: 0| OutputEn: 0| OpenDrain: 0| Pullup: 1| Pulldown: 0| Intr:0 
[06:38:10.770] I (65905) SPI_BUS: 删除 SPI 设备 (handle=0x0x3fca7160)
[06:38:10.770] I (65915) gpio: GPIO[7]| InputEn: 0| OutputEn: 0| OpenDrain: 0| Pullup: 1| Pulldown: 0| Intr:0 
[06:38:10.770] I (65925) SPI_BUS: 设备 (CS=5) 添加成功, 速度=1000000Hz, mode=1
[06:38:10.770] I (65925) SPI_BUS: 设备 (CS=6) 添加成功, 速度=1000000Hz, mode=1
[06:38:10.770] I (65935) SPI_BUS: 设备 (CS=7) 添加成功, 速度=8000000Hz, mode=0
[06:38:10.770] I (65945) MAIN: [2/5] 初始化 SIT1145...
[06:38:10.770] I (65945) SIT1145: 初始化 SIT1145-1 (CS=GPIO5)
[06:38:10.770] I (65955) SPI_BUS: SIT1145-1 TX(16bit): 02 07 | (无RX)
[06:38:10.770] I (65965) SPI_BUS: SIT1145-1 TX(16bit): 56 03 | (无RX)
[06:38:10.770] I (65965) SIT1145: SIT1145-1 写入: reg[0x26]=0x02
[06:38:10.770] I (65975) SPI_BUS: SIT1145-1 TX(16bit): 4C 02 | (无RX)
[06:38:10.770] I (65975) SIT1145: SIT1145-1 写入: reg[0x20]=0x32
[06:38:10.770] I (65985) SPI_BUS: SIT1145-1 TX(16bit): 40 32 | (无RX)
[06:38:10.770] I (65985) SPI_BUS: SIT1145-1 TX(16bit): 4D 00 | RX: 4D 02 
[06:38:10.770] I (65995) SPI_BUS: SIT1145-1 TX(16bit): 41 00 | RX: 41 32 
[06:38:10.770] I (66005) SPI_BUS: SIT1145-1 TX(16bit): 45 00 | RX: 45 A8 
[06:38:10.770] I (66005) SIT1145: SIT1145-1 读回验证: reg[0x26]=0x02, reg[0x20]=0x32, reg[0x22]=0xA8
[06:38:10.770] I (66015) SIT1145: SIT1145-1 验证通过 ✓
[06:38:10.770] I (66025) SIT1145: SIT1145-1 初始化完成 (retry=0)
[06:38:10.770] I (66025) SIT1145: 初始化 SIT1145-2 (CS=GPIO6)
[06:38:10.770] I (66035) SPI_BUS: SIT1145-2 TX(16bit): 02 07 | (无RX)
[06:38:10.770] I (66035) SPI_BUS: SIT1145-2 TX(16bit): 56 03 | (无RX)
[06:38:10.770] I (66045) SIT1145: SIT1145-2 写入: reg[0x26]=0x05
[06:38:10.770] I (66045) SPI_BUS: SIT1145-2 TX(16bit): 4C 05 | (无RX)
[06:38:10.770] I (66055) SIT1145: SIT1145-2 写入: reg[0x20]=0x32
[06:38:10.770] I (66065) SPI_BUS: SIT1145-2 T
[06:38:10.987] X(16bit): 40 32 | (无RX)
[06:38:10.987] I (66065) SPI_BUS: SIT1145-2 TX(16bit): 4D 00 | RX: 4D 05 
[06:38:10.987] I (66075) SPI_BUS: SIT1145-2 TX(16bit): 41 00 | RX: 41 32 
[06:38:10.987] I (66075) SPI_BUS: SIT1145-2 TX(16bit): 45 00 | RX: 45 A8 
[06:38:10.987] I (66085) SIT1145: SIT1145-2 读回验证: reg[0x26]=0x05, reg[0x20]=0x32, reg[0x22]=0xA8
[06:38:10.987] I (66095) SIT1145: SIT1145-2 验证通过 ✓
[06:38:10.987] I (66095) SIT1145: SIT1145-2 初始化完成 (retry=0)
[06:38:10.987] I (66105) MAIN: [3/5] 初始化 MCP2515...
[06:38:10.987] I (66115) MCP2515: MCP2515 初始化开始 (INT=GPIO8)
[06:38:10.987] I (66115) MCP2515: GPIO8 下降沿中断已安装
[06:38:10.987] I (66125) SPI_BUS: MCP2515 TX(8bit): C0 | (无RX)
[06:38:10.987] I (66135) MCP2515: 复位完成
[06:38:10.987] I (66135) SPI_BUS: MCP2515 TX(24bit): 02 2A 00 | (无RX)
[06:38:10.987] I (66135) SPI_BUS: MCP2515 TX(24bit): 02 29 90 | (无RX)
[06:38:10.987] I (66145) SPI_BUS: MCP2515 TX(24bit): 02 28 02 | (无RX)
[06:38:10.987] I (66145) MCP2515: 波特率配置完成 (CNF1=0x00, CNF2=0x90, CNF3=0x02)
[06:38:10.987] I (66155) SPI_BUS: MCP2515 TX(24bit): 02 60 60 | (无RX)
[06:38:10.987] I (66165) SPI_BUS: MCP2515 TX(24bit): 02 70 60 | (无RX)
[06:38:10.987] I (66165) MCP2515: 过滤器已关闭 (接收所有帧)
[06:38:10.987] I (66175) SPI_BUS: MCP2515 TX(24bit): 02 0C 00 | (无RX)
[06:38:10.987] I (66175) MCP2515: RXnBF 引脚中断已关闭
[06:38:10.987] I (66185) SPI_BUS: MCP2515 TX(24bit): 02 2B 03 | (无RX)
[06:38:10.987] I (66195) MCP2515: INT 引脚中断已开启 (RXB0IE + RXB1IE)
[06:38:10.987] I (66195) SPI_BUS: MCP2515 TX(24bit): 02 2C 00 | (无RX)
[06:38:10.987] I (66205) MCP2515: 中断标志已清除
[06:38:10.987] I (66205) SPI_BUS: MCP2515 TX(24bit): 02 0F 00 | (无RX)
[06:38:10.987] I (66215) SPI_BUS: MCP2515 TX(24bit): 03 0E 00 | RX: FF FF 00 
[06:38:10.987] I (66225) MCP2515: MCP2515 验证 (retry=0, CANSTAT=0x00, OPMOD=0 Normal ✓)
[06:38:10.987] I (66225) MAIN: [4/5] 挂载 SD 卡...
[06:38:10.987] I (66235) gpio: GPIO[14]| InputEn: 0| OutputEn: 0| OpenDrain: 0| Pullup: 1| Pulldown: 0| Intr:0 
[06:38:10.987] I (66245) gpio: GPIO[15]| InputEn: 0| OutputEn: 0| OpenDrain: 0| Pullup: 1| Pulldown: 0| Intr:0 
[06:38:10.987] I (66255) gpio: GPIO[2]| InputEn: 0| OutputEn: 0| OpenDrain: 0| Pullup: 1| Pulldown: 0| Intr:0 
[06:38:10.987] I (66265) gpio: GPIO[4]| InputEn: 0| OutputEn: 0| OpenDrain: 0| Pullup: 1| Pulldown: 0| Intr:0 
[06:38:10.987] I (66275) gpio: GPIO[12]| InputEn: 0| OutputEn: 0| OpenDrain: 0| Pullup: 1| Pulldown: 0| Intr:0 
[06:38:10.987] I (66275) gpio: GPIO[13]| InputEn: 0| 
[06:38:11.206] OutputEn: 0| OpenDrain: 0| Pullup: 1| Pulldown: 0| Intr:0 
[06:38:11.206] I (66395) gpio: GPIO[14]| InputEn: 0| OutputEn: 0| OpenDrain: 0| Pullup: 1| Pulldown: 0| Intr:0 
[06:38:11.206] I (66395) gpio: GPIO[15]| InputEn: 0| OutputEn: 0| OpenDrain: 0| Pullup: 1| Pulldown: 0| Intr:0 
[06:38:11.206] I (66405) gpio: GPIO[2]| InputEn: 0| OutputEn: 0| OpenDrain: 0| Pullup: 1| Pulldown: 0| Intr:0 
[06:38:11.206] I (66415) gpio: GPIO[4]| InputEn: 0| OutputEn: 0| OpenDrain: 0| Pullup: 1| Pulldown: 0| Intr:0 
[06:38:11.206] I (66425) gpio: GPIO[12]| InputEn: 0| OutputEn: 0| OpenDrain: 0| Pullup: 1| Pulldown: 0| Intr:0 
[06:38:11.206] I (66435) gpio: GPIO[13]| InputEn: 0| OutputEn: 1| OpenDrain: 0| Pullup: 0| Pulldown: 0| Intr:0 
[06:38:11.206] I (66475) gpio: GPIO[13]| InputEn: 0| OutputEn: 0| OpenDrain: 0| Pullup: 1| Pulldown: 0| Intr:0 
[06:38:11.206] Name: SD
[06:38:11.206] Type: SDHC/SDXC
[06:38:11.206] Speed: 20.00 MHz (limit: 20.00 MHz)
[06:38:11.206] Size: 29818MB
[06:38:11.206] CSD: ver=2, sector_size=512, capacity=61067264 read_bl_len=9
[06:38:11.206] SSR: bus_width=4
[06:38:11.206] I (66495) SD_CARD: SD 卡初始化成功
[06:38:12.903] I (67995) SD_LOG: sit1145: 新文件 /sdcard/sit1145/can_0320.csv 已创建 (编号=320)
[06:38:14.404] I (69495) SD_LOG: mcp2515: 新文件 /sdcard/mcp2515/can_0319.csv 已创建 (编号=319)
[06:38:14.404] I (69495) MAIN: [5/5] 注册句柄...
[06:38:14.404] I (69495) MCP2515: 已注册任务 (handle=0x0x3fca8768) 接收 MCP2515 中断通知
[06:38:14.404] I (69505) MAIN: ===== 外设重新初始化完成 =====
[06:38:14.721] Guru Meditation Error: Core  1 panic'ed (Interrupt wdt timeout on CPU1). 
[06:38:14.721] 
[06:38:14.721] Core  1 register dump:
[06:38:14.721] PC      : 0x4037a0f6  PS      : 0x00060834  A0      : 0x8037e55c  A1      : 0x3fca9220  
[06:38:14.721] A2      : 0x3c061330  A3      : 0xb33fffff  A4      : 0x0000abab  A5      : 0x00060a23  
[06:38:14.721] A6      : 0x00001946  A7      : 0x3fc9a740  A8      : 0x00000001  A9      : 0x00060823  
[06:38:14.721] A10     : 0x3c061330  A11     : 0x3fc9808c  A12     : 0x00000000  A13     : 0x4cc00001  
[06:38:14.721] A14     : 0x00000020  A15     : 0x0000abab  SAR     : 0x00000004  EXCCAUSE: 0x00000006  
[06:38:14.721] EXCVADDR: 0x00000000  LBEG    : 0x400556d5  LEND    : 0x400556e5  LCOUNT  : 0xfffffffe  
[06:38:14.721]

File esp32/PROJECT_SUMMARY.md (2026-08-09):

# ESP32-S3 车载终端工程 — 项目摘要

> **芯片型号:** ESP32-S3-WROOM-1-N8R2  
> **开发环境:** ESP-IDF v5.3.1  
> **目标平台:** ESP32-S3 (esp32s3)  
> **最后更新:** 2026-07-21

---

## 1. 硬件连接

### 1.1 调试串口
- **UART0 (GPIO43 TX, GPIO44 RX)**: 115200-8N1，所有调试信息输出
- **USB Serial/JTAG (GPIO19/20)**: 仅用于固件烧录

### 1.2 完整引脚分配

| 功能 | 组件 | GPIO | 说明 |
|---|---|:----:|---|
| **USB_D- / USB_D+** | 内置 | 19 / 20 | USB Serial/JTAG (烧录用) |
| **UART0_TX / UART0_RX** | 调试串口 | 43 / 44 | 控制台输出 (115200) |
| **SPI_MISO** | spi_bus | 16 | 共享 SPI 总线 |
| **SPI_MOSI** | spi_bus | 17 | |
| **SPI_SCK** | spi_bus | 18 | |
| **SIT1145-1_CS** | sit1145 (CAN1) | 5 | TWAI 路收发器 (1MHz, mode1) |
| **SIT1145-2_CS** | sit1145 (CAN2) | 6 | MCP2515 路收发器 (1MHz, mode1) |
| **MCP2515_CS** | mcp2515 | 7 | 外置 CAN 控制器 (8MHz, mode0) |
| **MCP2515_INT** | mcp2515 | 8 | 中断引脚 (下降沿触发) |
| **TWAI_TX** | twai | 10 | ESP32-S3 内置 CAN 控制器 TX |
| **TWAI_RX** | twai | 9 | ESP32-S3 内置 CAN 控制器 RX |
| **SD_CLK/CMD/D0/D1/D2/D3** | sd_card | 14/15/2/4/12/13 | SDMMC 4-bit 模式 |
| **SD_PWR_EN** | sd_card | 38 | SD 卡电源使能 |
| **4G_TX / 4G_RX** | modem_4g | 41 / 42 | 4G 模块 UART1 (私有协议) |
| **4G_RESET** | modem_4g | 47 | 4G 模块复位 |
| **3.8V_EN** | 电源控制 | 21 | 4G 模块/外部电源使能 |
| **BAT_ADC** | adc | 11 | 电池电压检测 (ADC2_CH0) |
| **BAT_MEAS_EN** | adc | 39 | ADC 通道开关 |
| **DS18B20** | ds18b20 | 40 | 单总线温度传感器 |
| **WAKE_IN** | 外部中断 | 1 | GPIO1 EXT1 高电平唤醒 |
| **USB_DN / USB_DP** | USB | 19 / 20 | 内置 USB Serial/JTAG |

---

## 2. CAN 通信架构

| CAN 总线 | 控制器 | 收发器 | 连接方式 |
|---|---|---|---|
| **CAN1** | ESP TWAI (内置) | SIT1145-1 (CS=GPIO5) | TWAI TX=GPIO10, RX=GPIO9 → SIT1145-1 |
| **CAN2** | MCP2515 (SPI, CS=GPIO7) | SIT1145-2 (CS=GPIO6) | MCP2515 → SIT1145-2 |

### SPI 总线共享设备 (SPI2_HOST)

| 设备 | CS | 速度 | SPI mode | 用途 |
|---|:--:|:----:|:---:|---|
| SIT1145-1 | GPIO5 | 1MHz | mode 1 | 配置 TWAI 路收发器 |
| SIT1145-2 | GPIO6 | 1MHz | mode 1 | 配置 MCP2515 路收发器 |
| MCP2515 | GPIO7 | 8MHz | mode 0 | CAN 控制器通信 |

> ESP-IDF 驱动会分别为每个设备独立管理时序，切换 CS 时自动切换时钟速度。

---

## 3. 多任务架构

### 3.1 任务分配

| 任务 | 绑核 | 优先级 | 触发方式 | 功能 |
|---|:----:|:---:|---|---|
| `mcp2515_task` | **Core0** | **最高 (24)** | GPIO 下降沿 ISR → Task Notification | SPI 读 MCP2515 → PSRAM 缓冲区 + 解析 |
| `twai_task` | **Core1** | **最高 (24)** | TWAI Alert(RXI) 硬件中断 | 读 TWAI RX FIFO → PSRAM 缓冲区 + 解析 |
| `sd_write_task` | Core1 | 最低 (1) | 共享计数信号量永久阻塞 | 缓冲区满 → 写入 SD 卡 CSV 文件 |
| `sensor_task` | Core1 | 5 | `vTaskDelay(1000)` | 温度/电压/状态打印 + 电源管理空闲检测 |

### 3.2 数据流

```
CAN 数据帧到达
    │
    ├→ mcp2515_task / twai_task 收到
    │   ├→ can_buffer_write_csv()      ← PSRAM 双缓冲区 (所有数据备份到 SD)
    │   └→ can_parser_process()        ← 解析关心 ID, 更新 g_state
    │
    └→ PSRAM 缓冲区满 (64KB)
        └→ 共享信号量通知 sd_write_task
            └→ 追加写入 SD 卡 CSV 文件
```

---

## 4. 工程结构 (组件化)

```
sample_project/
├── CMakeLists.txt                 # EXTRA_COMPONENT_DIRS=components
├── sdkconfig
├── components/                    # 自定义组件目录 (14 个)
│   ├── board_config/              # 板级引脚定义
│   ├── spi_bus/                   # SPI2_HOST 共享总线 + 设备名映射
│   ├── sit1145/                   # SIT1145AQ CAN 收发器驱动
│   ├── mcp2515/                   # MCP2515 CAN 控制器驱动 (含重试)
│   ├── twai/                      # ESP TWAI CAN 驱动封装 (125kbps, Alert)
│   ├── sd_card/                   # SD 卡 FATFS 挂载/读写
│   ├── sd_logger/                 # SD 卡 CSV 日志写入器 (自动编号+追加)
│   ├── can_buffer/                # PSRAM 双缓冲区管理器 (降级: 内部 RAM)
│   ├── can_parser/                # CAN 数据帧解析器 + GPS 状态变量
│   ├── modem_4g/                  # 4G 模块 (UART + AT 命令)
│   ├── ds18b20/                   # 单总线温度传感器
│   ├── adc/                       # 电池电压检测
│   ├── power_manager/             # 电源管理 (三种模式 + GPIO 唤醒)
│   └── gps_poller/                # GPS 轮询器 (UART1 收发 + KEY=VALUE 解析)
├── main/
│   ├── CMakeLists.txt
│   └── main.c                     # 主入口: 唤醒判断 + 初始化 + 4 任务
├── WAKEUP_CONFIG_SUMMARY.md
└── PROJECT_SUMMARY.md
```

---

## 5. 各组件 API 速览

### board_config
```c
#include "board_config.h"
// 引脚宏: PIN_SPI_MOSI, PIN_SIT1_CS, PIN_TWAI_TX, PIN_WAKE_IN, PIN_UART0_TX 等
```

### spi_bus
```c
spi_bus_init_board(mosi, miso, sck);                        // 初始化 SPI2_HOST
spi_bus_add_device_custom(cs, clock_hz, mode, &handle);     // 添加 SPI 设备
spi_bus_del_device(handle);                                  // 删除 SPI 设备 (light sleep 唤醒)
spi_bus_set_device_name(handle, "SIT1145-1");                // SPI 日志带设备名
spi_bus_write_reg(handle, addr, data);                      // 写 16-bit 寄存器
spi_bus_read_reg(handle, addr, &data);                      // 读 16-bit 寄存器
spi_bus_transfer(handle, tx, rx, bit_len);                  // 原始全双工传输 + HEX 日志
```

### sit1145
```c
sit1145_init(SIT1145_DEV_1, handle);           // 初始化 (写入0x26→0x20, 三寄存器验证)
sit1145_verify_chip_id(SIT1145_DEV_1);          // 验证芯片 ID (0x74)
sit1145_read_reg(dev, reg, &val);               // 读寄存器
sit1145_write_reg(dev, reg, data);              // 写寄存器 (地址编码: (reg<<1)|R/W)
```

### mcp2515
```c
mcp2515_init(handle, int_pin);                  // 初始化 (重试 5 次)
mcp2515_register_task(task_handle);             // 注册通知任务
mcp2515_send_frame(&frame);                     // 发送 (0x40 装载 + 0x81 快速发送)
mcp2515_receive_frame(&frame);                  // 接收 (0xB0→0x90→0x05)
mcp2515_has_interrupt();                        // 检查 INT 引脚电平
```

### twai
```c
twai_driver_init(TX_PIN, RX_PIN);               // 初始化 (125kbps, rx_queue=128)
twai_driver_start();                             // 启动 TWAI + Alert(RXI+DOI)
twai_driver_stop();                              // 停止
twai_driver_deinit();                            // 卸载驱动 (light sleep 进入前)
twai_driver_transmit(&frame, ms);                // 发送
twai_driver_receive(&frame, ms);                 // 接收 (带日志)
twai_driver_wait_rx(timeout_ms);                 // Alert 阻塞等待 RX 数据
```

### sd_card
```c
sd_card_init(pwr_en_pin);                       // 挂载 SD 卡
sd_card_deinit();                               // 卸载
sd_card_write_file(path, data, len);            // 写文件
sd_card_read_file(path, buf, size, &out);       // 读文件
```

### sd_logger
```c
sd_logger_init("sit1145");                      // 创建新文件 + CSV 头
sd_logger_write("mcp2515", data, len);          // 追加写入
// 目录: /sdcard/sit1145/can_0001.csv
// 格式: timestamp_ms,can_id,dlc,d0~d7,extended,rtr
```

### can_buffer
```c
can_buffer_init(&ctx, "mcp2515");               // 分配 2 缓冲区 (PSRAM 优先, 降级内部 RAM)
can_buffer_write_csv(&ctx, id, dlc, data, ...);  // 写 CSV 行
can_buffer_get_full(&ctx, &buf, &size);          // 获取满缓冲区
can_buffer_release_full(&ctx);                   // 释放满缓冲区
```

### can_parser
```c
can_parser_process(can_id, data, dlc);           // 解析 CAN 帧, 更新 g_state
// g_state 包含: lat/lng/speed/net/csq/fix/sat/hdop/altitude/height/gps_time
//               voltage/fuel/temperature/rpm/throttle/车门/车窗/手刹/点火 等
```

### modem_4g
```c
modem_4g_init(tx, rx, reset, baud);             // 初始化 UART1
modem_4g_send_at("AT\r\n", resp, size, ms);     // 发送 AT 命令
```

### gps_poller
```c
gps_poller_uart_init();                          // GPIO21=高, 初始化 UART1
gps_poller_run_cycle();                          // 发送 STATUS?, 解析 KEY=VALUE, FIX=1 发 JSON
gps_poller_uart_deinit();                        // 关闭 UART1, GPIO21=低
```

### power_manager
```c
power_manager_init();                            // 初始化为 NORMAL 模式
power_manager_tick(now_ms);                      // 每秒检查空闲超时 (1min)
power_manager_should_standby();                  // 是否应进入待机
power_manager_enter_standby();                   // 进入 light sleep (3min GPS)
power_manager_enter_sleep();                     // 进入 deep sleep (仅 GPIO1)
power_manager_is_auto_wake();                    // 是否为定时器自主唤醒
power_manager_set_mode(mode);                    // 设置电源模式
```

---

## 6. sdkconfig 关键配置

```c
// 控制台: UART0 (GPIO43/44)
CONFIG_ESP_CONSOLE_UART_DEFAULT=y
CONFIG_ESP_CONSOLE_UART_NUM=0

// Flash 8MB & PSRAM
CONFIG_ESPTOOLPY_FLASHSIZE_8MB=y
CONFIG_SPIRAM=y
CONFIG_SPIRAM_MODE_QUAD=y
CONFIG_SPIRAM_SPEED_40M=y

// CPU 主频
CONFIG_ESP_DEFAULT_CPU_FREQ_MHZ=160
```

---

## 7. 电源管理模式 (核心)

### 三种模式

| 模式 | 描述 | 触发条件 | 4G 电源 | GPIO1 | GPIO42 |
|---|---|---|:---:|:-----:|:---:|
| **NORMAL** | 全速运行 | 上电 / GPIO 唤醒 | 高 | 输入 | UART1 |
| **STANDBY** | Light sleep | 1min 无 CAN 报文 | 高 | EXT1 唤醒 | IO MUX 唤醒 |
| **SLEEP** | Deep sleep | 定时器唤醒 3 次 | 低 | EXT1 唤醒 | 高阻态 |

### Light sleep 流程

```
正常模式 → 1分钟无CAN → light sleep (3min)
  3min 到 → [定时器唤醒]
           → GPIO21=高 (保持)
           → 初始化 UART1
           → 发送 STATUS?
           → 解析 KEY=VALUE (FIX=1 → 更新 g_state + 发 JSON)
           → 2 分钟窗口结束
           → 回到 light sleep (s_wake_count++)
           → 3 次后进 deep sleep
```

### Deep sleep 流程

```
deep sleep → 3min 到 → 重启
           → GPIO21=高
           → GPS 轮询 2min
           → GPIO21=低
           → deep sleep (循环)
```

### 唤醒源

| 唤醒源 | 作用阶段 | 唤醒原因码 | 操作 |
|---|---|:---:|---|
| GPIO1 (EXT1) | Light/Deep sleep | 1 | 全初始化外设 |
| GPIO42 (IO MUX) | Light sleep only | 2 | 全初始化外设 |
| RTC 定时器 | Light sleep only | 4 | GPS 轮询 |

---

## 8. 初始化日志 (当前版本)

```
I (786) MAIN: 外部唤醒/上电: 全初始化
I (786) MAIN: ===== 全初始化 =====
I (846) SPI_BUS: 初始化 SPI2_HOST 总线: MOSI=17, MISO=16, SCK=18
I (846) SPI_BUS: 总线初始化成功
I (846) SPI_BUS: 设备 (CS=5) 添加成功, 速度=1000000Hz, mode=1
I (846) SPI_BUS: 设备 (CS=6) 添加成功, 速度=1000000Hz, mode=1
I (856) SPI_BUS: 设备 (CS=7) 添加成功, 速度=8000000Hz, mode=0
I (866) SIT1145: SIT1145-1 写入: reg[0x26]=0x02
I (876) SIT1145: SIT1145-1 写入: reg[0x20]=0x32
I (896) SIT1145: SIT1145-1 读回验证: reg[0x26]=0x02, reg[0x20]=0x32, reg[0x22]=0xA8
I (916) SIT1145: SIT1145-1 验证通过 ✓
I (926) SIT1145: SIT1145-2 写入: reg[0x26]=0x05
I (966) SIT1145: SIT1145-2 读回验证: reg[0x26]=0x05, reg[0x20]=0x32, reg[0x22]=0xA8
I (1006) SIT1145: SIT1145-2 验证通过 ✓
I (1026) SIT1145: SIT1145-1 Chip ID = 0x74 ✓
I (1036) SIT1145: SIT1145-2 Chip ID = 0x74 ✓
I (1226) MCP2515: MCP2515 验证 (retry=1, CANSTAT=0x00, OPMOD=0 Normal ✓)
I (1266) TWAI: TWAI 驱动安装成功 (125kbps)
I (1266) TWAI: TWAI 通信启动, Alert 已配置 (RXI + DOI)
I (1516) SD_CARD: SD 卡初始化成功
I (2886) MAIN: PSRAM: 2097152 bytes
I (2906) CAN_BUF: mcp2515: 双缓冲区初始化完成 (PSRAM, 2×65536 bytes)
I (3956) MAIN: ===== 全初始化完成 =====

--- 进入 light sleep 后 ---
I (64426) POWER_MGR: 进入 light sleep (3min GPS, GPIO1/42 唤醒)
I (64446) POWER_MGR: 唤醒 原因=4(RTC定时器)
I (64475) MAIN: 定时器唤醒 (wake_count=0/3)
I (64475) GPS_POLL: ===== GPS 轮询: UART1 初始化 =====
I (64585) GPS_POLL: --- 第 1 次 STATUS? (已用 0 秒) ---
```

---

## 9. PSRAM 缓冲区分配

| 缓冲区 | 大小 | 数量 | 总占用 | 分配位置 |
|---|:----:|:----:|:---:|---|
| MCP2515 双缓冲区 | 64KB | 2 | 128KB | PSRAM (降级: 16KB 内部 RAM) |
| TWAI 双缓冲区 | 64KB | 2 | 128KB | PSRAM (降级: 16KB 内部 RAM) |
| **合计** | | **4个** | **256KB** | `heap_caps_malloc(size, MALLOC_CAP_SPIRAM)` |

---

## 10. 版本变更记录

| 日期 | 变更 | 说明 |
|---|---|---|
| 2026-07-15 | 初始组件化 | 9 个组件, 单任务轮询 |
| 2026-07-15 | 多任务架构 | 4 任务 Core0+Core1, PSRAM 双缓冲区, SD CSV 日志 |
| 2026-07-18 | **电源管理** | power_manager 组件: 三种模式 |
| 2026-07-18 | GPIO 唤醒调试 | Light sleep 唤醒问题排查 |
| 2026-07-18 | RTC GPIO API | rtc_gpio_init + EXT1 + pd_config |
| 2026-07-18 | Deep sleep 唤醒 | deep sleep 能正常唤醒 |
| 2026-07-18 | UART0 调试串口 | 控制台从 USB_JTAG 切换到 UART0 |
| 2026-07-20 | **GPS 轮询** | gps_poller 组件 |
| 2026-07-20 | 唤醒类型判断 | RTC_DATA_ATTR 标志 + app_main 判断 |
| 2026-07-20 | MCP2515 重试 | 复位重试 5 次 |
| 2026-07-20 | Light sleep 唤醒修复 | 删除 GPIO42 IO MUX 冲突 |
| 2026-07-21 | **完整 sleep 循环** | light sleep 3min × 3 → deep sleep 3min GPS |
| 2026-07-21 | wake_count 简化 | 单个 RTC 变量控制 light→deep 切换 |
| 2026-07-21 | STATUS? 直发 | GPS 轮询不再等待 GPS=OK |
| 2026-07-21 | SPI 休眠标志 | s_periph_initialized 防止 GPS 轮询时误休眠 |
| 2026-07-21 | GPIO42 唤醒恢复 | IO MUX 高电平唤醒重新加入 |
| 2026-07-21 | GPS 超时修复 | uart_read_bytes 200ms→2000ms |

---

## 11. 踩坑记录

### 11.1 PSRAM 模式错误
- N8R2 模组 PSRAM 是 **Quad SPI** 模式, 非 Octal

### 11.2 SIT1145 地址编码
- R/W 位在 **LSB (bit0)**: `ADDR_W = (reg<<1)|0`, `ADDR_R = (reg<<1)|1`

### 11.3 SIT1145 SPI mode
- SIT1145 使用 **mode 1** (下降沿采样)

### 11.4 Light sleep 无法唤醒 (已解决)
- 原因: GPIO1 未配置 `rtc_gpio_` API + `esp_sleep_pd_config(RTC_PERIPH, ON)`
- 原因: ESP-IDF 默认 `sleep: Configure to isolate all GPIO pins`
- 解决: `rtc_gpio_init + gpio_sleep_sel_dis + EXT1 + pd_config`

### 11.5 IO MUX 与 EXT1 冲突 (已解决)
- 同时使用 `esp_sleep_enable_gpio_wakeup()` 和 `esp_sleep_enable_ext1_wakeup()` 导致立即唤醒
- 解决: 只能二选一，GPIO1 用 EXT1，GPIO42(非 RTC) 用 IO MUX

### 11.6 Deep sleep 5 分钟自动重启 (已解决)
- 原因: Light sleep 的定时器残留到 deep sleep
- 解决: `esp_sleep_disable_wakeup_source(ESP_SLEEP_WAKEUP_TIMER)`

### 11.7 Light sleep 唤醒后 SPI 冲突 (已解决)
- 原因: `spi_bus_init_board()` 重复调用
- 解决: wake_reinit 中跳过总线初始化, 删除旧设备再添加

### 11.8 GPS 轮询 UART 收不到数据 (已解决)
- 原因: `uart_read_bytes()` 每次轮询超时 200ms 太短, 模块首字节在 200ms 后才到达
- 解决: 超时改为 2000ms

---

## 12. 常用命令

```bash
# 编译
idf.py build

# 烧录 (USB 线, 替换为你的串口号)
idf.py -p COM17 flash

# 查看 UART0 调试输出 (USB 转串口模块接 GPIO43/44)
# 串口助手: COMxx 115200-8N1
```

---

## 13. TO-DO / 后续改进

- [x] 基础 CAN 收发 (MCP2515 + TWAI)
- [x] 多任务架构 (4 任务)
- [x] SD 卡 CSV 日志
- [x] 三种电源模式 (NORMAL / STANDBY / SLEEP)
- [x] GPIO1 EXT1 高电平唤醒
- [x] GPS 轮询 (每 3 分钟, STATUS? 查询)
- [x] Light→Deep sleep 切换 (3 次后)
- [x] Flash 大小 8MB 修正
- [ ] DS18B20 温度传感器 (待硬件连接后验证)
- [ ] CPU 主频提升到 240MHz
- [ ] 4G 模块 AT 命令通信完善
- [ ] 外部 RTC 时间同步 (用 GPS TIME 校准)
- [ ] WiFi/BLE 功能测试
- [ ] 解析串口数据逻辑优化

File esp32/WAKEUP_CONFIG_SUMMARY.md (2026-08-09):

# ESP32-S3 唤醒配置问题 — 待排查

## 硬件信息

| 项目 | 值 |
|---|-----|
| 芯片 | ESP32-S3-WROOM-1-N8R2 |
| 唤醒引脚 | GPIO1 (无外部上下拉电阻) |
| 唤醒信号 | 外部手动加 3.3V 脉冲电压 (秒级) |

## 目标行为

1. **正常模式** → 2 分钟无 CAN 报文 → **待机模式 (light sleep)**
2. **待机模式** → GPIO1 高电平脉冲 → 应唤醒回到正常模式
3. **待机模式** → 5 分钟定时器到期 → **休眠模式 (deep sleep)**
4. **休眠模式** → GPIO1 高电平脉冲 → 应唤醒重启芯片

## 当前现象

- 进入 light sleep / deep sleep 成功（终端有打印）
- GPIO1 加 3.3V 高电平脉冲后 **没有任何反应**（终端无打印）
- 说明 GPIO1 没有触发唤醒

## 代码片段

所有唤醒配置代码均在 `components/power_manager/power_manager.c` 中。

### ① 待机模式 (light sleep) — power_manager_enter_standby()

```c
/* ===== 进入 light sleep 前的唤醒配置 ===== */

/* GPIO1: 输入 + 内部下拉, EXT1 高电平唤醒 */
gpio_set_direction(GPIO_NUM_1, GPIO_MODE_INPUT);
gpio_set_pull_mode(GPIO_NUM_1, GPIO_PULLDOWN_ONLY);
esp_sleep_enable_ext1_wakeup(1ULL << GPIO_NUM_1, ESP_EXT1_WAKEUP_ANY_HIGH);

/* 5 分钟 RTC 定时器唤醒 */
esp_sleep_enable_timer_wakeup(SLEEP_TIMER_TIMEOUT_US);  // 5*60*1000000 = 300000000 us

/* 进入 light sleep */
ESP_LOGI(TAG, "进入 light sleep, 5 分钟定时器已设");
fflush(stdout);
esp_light_sleep_start();

/* ===== 唤醒后处理 ===== */
esp_sleep_wakeup_cause_t cause = esp_sleep_get_wakeup_cause();
ESP_LOGI(TAG, "从 light sleep 唤醒, 原因: %d", cause);

// 恢复 GPIO38/39 电源控制
// ...

if (cause == ESP_SLEEP_WAKEUP_TIMER) {
    // 5 分钟无唤醒 → 进入休眠模式 (deep sleep)
    power_manager_enter_sleep();
}

// GPIO 唤醒 → 回到正常模式
return ESP_OK;  // 返回后重新初始化外设
```

### ② 休眠模式 (deep sleep) — power_manager_enter_sleep()

```c
/* ===== 进入 deep sleep 前的唤醒配置 ===== */

/* GPIO1: 输入 + 内部下拉, EXT1 高电平唤醒 */
gpio_set_direction(GPIO_NUM_1, GPIO_MODE_INPUT);
gpio_set_pull_mode(GPIO_NUM_1, GPIO_PULLDOWN_ONLY);
esp_sleep_enable_ext1_wakeup(1ULL << GPIO_NUM_1, ESP_EXT1_WAKEUP_ANY_HIGH);

/* 进入 deep sleep (不返回) */
esp_deep_sleep_start();
```

### ③ 待机前关闭的 GPIO

```c
/* 关闭 SD 卡电源 */
gpio_set_level(PIN_SD_PWR_EN, 0);   // GPIO38
/* 关闭 ADC 测量 */
gpio_set_level(PIN_BAT_MEAS_EN, 0); // GPIO39
```

## 已排查的方向

| 方向 | 结果 |
|---|---|
| `GPIO_INTR_HIGH_LEVEL` + `esp_sleep_enable_gpio_wakeup()` 旧版 IO MUX 路径 | 无效 |
| `ESP_GPIO_WAKEUP_GPIO_HIGH` + `esp_sleep_enable_gpio_wakeup(GPIO, level)` 新版 API | 编译不通过 (API 不存在) |
| 旧版 + IO MUX 混合 EXT1 (同时调用 `esp_sleep_enable_gpio_wakeup()` 和 `esp_sleep_enable_ext1_wakeup()`) | **互相冲突** — 全部唤醒失效 |
| 仅 EXT1 (`esp_sleep_enable_ext1_wakeup`) + RTC 定时器 | **当前代码, 仍然无效** |
| GPIO42 加入 EXT1 | 失败 — GPIO42 不是 RTC IO |

## 核心疑问

1. ESP32-S3 上，对于 **GPIO1 (RTC IO)**，light sleep 和 deep sleep 的 EXT1 唤醒最低配置步骤是否就是：
   ```
   gpio_set_direction(GPIO_NUM_1, GPIO_MODE_INPUT);
   gpio_set_pull_mode(GPIO_NUM_1, GPIO_PULLDOWN_ONLY);
   esp_sleep_enable_ext1_wakeup(1ULL << GPIO_NUM_1, ESP_EXT1_WAKEUP_ANY_HIGH);
   esp_light_sleep_start(); // 或 esp_deep_sleep_start()
   ```
   还有没有缺失的步骤？

2. `esp_sleep_enable_timer_wakeup()` 和 `esp_sleep_enable_ext1_wakeup()` 是否可以同时使用？

3. 是否需要额外调用 `esp_sleep_pd_config()` 之类的函数来保持唤醒电路供电？

4. GPIO1 无外部上下拉电阻，仅靠内部 45kΩ 下拉，是否足够可靠？是否必须在 GPIO1 加外部 10kΩ 下拉？

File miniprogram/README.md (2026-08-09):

# 车辆监控微信小程序

基于 **微信云开发** 的车载终端监控小程序，配合 ESP32 车载终端（`../esp32/`）与 4G 物联网模块银尔达 M100PG-DTU（`../iot/`）使用，实时展示车辆位置、行驶状态、历史轨迹与告警推送。

## 功能特性

- 🗺️ **实时位置地图** — 车辆定位、定位精度圈（HDOP）、手机与车辆距离
- 🛤️ **轨迹回放** — 30 秒采样的历史轨迹（`trochoid` 集合），增量合并绘制
- 🚗 **CAN 实时状态** — 车门/车窗/手刹/点火/灯光/空调/油门/转速/安全带等
- 📈 **历史图表** — 电压 / 燃油 / 车内温度曲线（近 24 小时 / 7 天 / 30 天）
- 🔔 **告警推送** — 非法移动 + 异常离线检测，微信订阅消息推送
- ⚡ **资源优化** — 全局 15 秒轮询 + 页面缓存 + 后台暂停，节省云资源

## 目录结构

```
├── miniprogram/                  # 小程序前端
│   ├── app.js                    # 全局轮询器（每15秒拉取车辆数据+告警）
│   ├── app.json / app.wxss
│   └── pages/
│       ├── index/                # 首页：地图、轨迹、告警红点
│       └── detail/               # 详情页：实时状态、历史图表
├── cloudfunctions/               # 云函数
│   ├── upload/                   # 主后端：HTTP 数据接收 /latest /history /alerts
│   ├── alertChecker/             # 定时检测（每20分钟）：异常离线 + 推送
│   └── notify/                   # 订阅消息：openid 注册 / 发送
├── project.config.json           # 小程序项目配置
├── DATA_DOC.md                   # 数据对接文档（字段定义/告警链路/部署）
└── uploadCloudFunction.sh        # 云函数上传脚本
```

## 数据流

```
终端(GPS+CAN) ──HTTP POST──▶ upload 云函数
                                │ 写入
                 ┌──────────────┼────────────────┐
                 ▼              ▼                ▼
              device        can_history      trochoid
             (最新状态)      (完整历史)       (轨迹30s采样)
                                │
                 ┌──────────────┼────────────────┐
                 ▼              ▼                ▼
             alerts          subscribers    alertChecker(定时)
             告警记录          订阅用户          └──▶ notify ──▶ 订阅消息
```

## 部署步骤

1. **导入项目**：微信开发者工具 → 导入 `miniprogram/` 所在目录（本仓库根）
2. **替换占位符**（本仓库已脱敏，部署前需填回你自己的配置）：
   | 占位符 | 说明 | 位置 |
   |--------|------|------|
   | `YOUR_APPID` | 小程序 AppID | `project.config.json` |
   | `YOUR_ENV_ID` | 云开发环境 ID | `miniprogram/app.js`、`cloudfunctions/upload/app.js` |
   | `YOUR_ENV_ID.tcloudbase.com` | 云开发域名 | `miniprogram/app.js`、各页面 |
   | `YOUR_TEMPLATE_ID` | 订阅消息模板 ID | `alertChecker/index.js`、`notify/index.js`、`pages/index/index.js` |
   | `YOUR_MQTT_HOST` | MQTT 服务器地址 | `pages/detail/detail.js` |
3. **开通云开发**：创建环境 → 创建集合 `device`、`can_history`、`trochoid`、`alerts`、`subscribers`
4. **部署云函数**：在开发者工具中对 `upload`、`alertChecker`、`notify` 分别「上传并部署：云端安装依赖」
5. **配置定时触发器**：`alertChecker/config.json` 已配置每 20 分钟触发
6. **添加请求域名**：在微信公众平台 → 开发管理 → 服务器域名，添加云开发域名到 request 合法域名

## 相关文档

- [DATA_DOC.md](DATA_DOC.md) — 完整的数据对接文档（字段定义、数据库集合、告警链路、部署说明）
- ESP32 固件见 `../esp32/`，4G 桥接脚本见 `../iot/`

## 许可证

本项目基于 GPL-3.0 开源，详见根目录 `LICENSE`。

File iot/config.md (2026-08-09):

# 4G 物联网模块（银尔达 M100PG-DTU 固件版）— 网络通道配置

> 本文档对应银尔达平台「网络通道」配置界面，供 `espBridge.lua` 任务使用。
> ⚠️ 以下均为**示例占位**，部署时请替换为你自己的服务器地址、MQTT 凭据与设备 ID。

## 网络通道 1 — HTTP（数据上报）

| 配置项 | 值 |
|---|-----|
| 网络通讯协议 | HTTP |
| 绑定通讯串口 | UART |
| 请求方法 | POST |
| 服务器地址 | `https://YOUR_ENV_ID.tcloudbase.com` |
| 服务器端口 | 443 |
| 请求的 URL | `/upload` |
| 等待超时时间 | 30 |
| 自定义头部 | `Content-Type=application/json` |
| 返回数据过滤 | 过滤 |
| 登录注册信息 | 不发送 |
| 支持 IPv6 | 否 |
| 支持 SSL | 无证书加密 |

上报字段定义见小程序端 `DATA_DOC.md`（POST /upload）。

## 网络通道 2 — MQTT（下行指令 / 状态透传）

| 配置项 | 值 |
|---|-----|
| 网络通讯协议 | MQTT |
| 绑定通讯串口 | UART |
| 心跳包发送间隔 | 60 秒 |
| 服务器地址 | `YOUR_MQTT_HOST` |
| 服务器端口 | 8883 |
| 登录客户端 ID | `YOUR_DEVICE_ID`（如 car001） |
| 登录用户名 | `YOUR_DEVICE_ID` |
| 登录密码 | `YOUR_MQTT_PASSWORD` |
| 协议版本 | 3.1.1 |
| 清除会话 | 离线自动销毁 |
| 订阅消息主题 | `YOUR_DEVICE_IDdown`（如 car001down） |
| 发布消息主题 | `YOUR_DEVICE_IDup`（如 car001up） |
| 支持 SSL | 无证书加密 |

> MQTT 通道用于下行指令（例如远程控制）与透传数据，HTTP 通道用于车辆状态上报。

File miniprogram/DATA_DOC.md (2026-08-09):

# 车辆监控小程序 — 数据对接文档

> 本文档说明完整的后端字段定义、数据库集合、接口、告警推送系统及缓存策略，覆盖当前项目全部数据链路。

---

## 🏗️ 系统架构总览

```
┌─────────────┐      ┌──────────────────────┐      ┌─────────────┐
│   终端设备    │ POST │  upload 云函数（HTTP） │      │   小程序前端  │
│  (GPS + CAN) │─────▶│  · 数据接收/字段转换    │      │  每15秒轮询   │
└─────────────┘      │  · 非法移动检测          │      └──────┬──────┘
                     │  · 异常离线检测(latest)   │             │
                     │  · /alerts 查询/已读     │◀────────────┘
                     └──────────┬───────────────┘
                                │ 写入
                 ┌──────────────┼───────────────┐
                 ▼              ▼               ▼
           ┌──────────┐  ┌──────────┐  ┌──────────────┐
           │  device  │  │can_history│  │  trochoid    │
           │ 最新状态  │  │  完整历史  │  │ 轨迹(30s采样) │
           └──────────┘  └──────────┘  └──────────────┘
                                │
                 ┌──────────────┼───────────────┐
                 ▼              ▼               ▼
           ┌──────────┐  ┌──────────┐  ┌──────────────┐
           │  alerts  │  │subscribers│  │  alertChecker│
           │  告警记录 │  │  订阅用户  │  │ 定时云函数     │
           └──────────┘  └──────────┘  └──────────────┘
                                                     │
                                                     ▼
                                            ┌──────────────────┐
                                            │  notify 云函数    │
                                            │ 订阅消息推送        │
                                            └──────────────────┘
```

---

## 📂 文件位置

| 文件 | 说明 |
|---|---|
| `cloudfunctions/upload/app.js` | 主后端：数据接收、协调转换、接口 |
| `cloudfunctions/alertChecker/index.js` | 定时云函数：异常离线检测 + 推送（每20分钟） |
| `cloudfunctions/alertChecker/config.json` | 定时触发器配置 |
| `cloudfunctions/notify/index.js` | 订阅消息云函数：注册 openid / 发送 |
| `miniprogram/app.js` | 全局轮询器（车辆数据 + 告警，每15秒） |
| `miniprogram/pages/index/index.js` | 首页：地图、轨迹、定位精度圈、告警红点 |
| `miniprogram/pages/detail/detail.js` | 详情页：位置、实时状态、历史图表 |

---

## 📊 终端上传字段定义（POST /upload）

### 基础位置字段

| 字段 | 类型 | 必须 | 说明 |
|---|---|:--:|---|
| `deviceId` | String | ✅ | 设备ID（固定 "car001"） |
| `lat` | Number | ✅ | WGS84 纬度 |
| `lng` | Number | ✅ | WGS84 经度 |
| `speed` | Number | | GPS 速度 (km/h) |
| `voltage` | Number | | 电压 (V) |
| `fuel` | Number | | 燃油 (%) |
| `temperature` | Number | | 车内温度 (°C) |
| `mileage` | Number | | 总里程 (km) |
| `direction` | Number | | 方向角 (°) |
| `csq` | Number | | 4G 信号质量 |
| `gps` | Number | | 定位开关 (1=开 0=关) |
| `altitude` | Number | | 原始 GPS 海拔 (m) |
| `height` | Number | | 大地水准面差距 (m) |
| `satellites` | Number | | GPS 卫星数 |
| `hdop` | Number | | 水平精度因子 |
| `fix` | Number | | 定位修复状态 |
| `time` | Number | | Unix 秒时间戳 |

### CAN 总线字段

| 字段 | 类型 | 说明 |
|---|---|---|
| `door` | String | 车门状态 "00000"（0=关 1=开，左前/右前/左后/右后/尾门） |
| `window` | String | 车窗状态 "0000"（0=升 1=降，左前/右前/左后/右后） |
| `handbrake` | Number | 手刹 (1=拉起 0=放下) |
| `ignition` | Number | 点火 (1=点火 0=熄火) |
| `clutch` | Number | 离合器 (1=踩下 0=未踩) |
| `brake` | Number | 刹车 (1=踩下 0=未踩) |
| `light` | Number | 灯光 (0=关 1=近光 2=远光) |
| `ac` | Number | 空调 (1=开 0=关) |
| `cd` | Number | 中控屏 (1=开 0=关) |
| `cdVolume` | Number | 音量 |
| `seatbelt` | Number | 安全带 (1=系上 0=未系) |
| `passenger` | Number | 乘客检测 |
| `throttle` | Number | 油门开度 (%) |
| `rpm` | Number | 发动机转速 (rpm) |
| `wheelSpeed` | Number | 轮速 (km/h) |

### 芯片状态字段

| 字段 | 类型 | 说明 |
|---|---|---|
| `sit1145_1_init` | Number | SIT1145-1 状态 (1=正常 0=故障) |
| `sit1145_2_init` | Number | SIT1145-2 状态 (1=正常 0=故障) |
| `mcp2515_init` | Number | MCP2515 状态 (1=正常 0=故障) |

---

## 📐 后端计算/转换字段

由 `cloudfunctions/upload/app.js` 的 `buildFullData()` 计算生成：

| 字段 | 类型 | 说明 |
|---|---|---|
| `locationValid` | Boolean | 是否收到有效经纬度 |
| `gcj02_lat` / `gcj02_lng` | Number | WGS84 → GCJ02 转换结果（小程序地图用） |
| `correctedAltitude` | Number | **校准后海拔 = altitude + height** |
| `carState` | String | 车辆状态（online/offline/lowpower/waiting） |
| `lastDataTime` | Number | 最后收到数据时间（用于离线检测，每次都更新） |
| `time` | Number | 数据时间戳 |

### ⚠️ 无经纬度时的保护逻辑

终端上传无 `lat`/`lng` 时：

```
POST /upload:
  · device  → update() 保留旧坐标，设 locationValid=false，更新 lastDataTime
  · can_history → 正常写入（CAN 数据仍有价值）
  · trochoid   → 跳过（无轨迹节点）
  · 前端：显示"GPS信号暂失 (上次更新时间)"，地图不跳转
```

---

## 🔌 接口定义

### 接口 1：终端数据上传（POST /upload）

```
POST https://YOUR_ENV_ID.tcloudbase.com/upload
Content-Type: application/json
```

**返回：** `{ "code": 0, "msg": "upload success" }`

**逻辑：**
1. 更新 `device` 集合（始终写入，无位置时保留旧坐标）
2. 写入 `can_history`（每次无条件写入）
3. 写入 `trochoid`（每 30 秒一次，仅当有经纬度）
4. **非法移动检测**：offline 状态且位置变化 >100米 → 写入 `alerts`

---

### 接口 2：获取车辆最新数据（GET /latest）

```
GET .../upload/latest
```

返回 `device` 集合完整文档（含全部计算字段）。

**附加逻辑：** 前端每 15 秒调用此接口：
- 超过 60 秒无数据 → `carState` 标记 offline
- waiting 超过 180 秒 → offline
- **异常离线检测**：超过阈值（默认 10 分钟，见 `upload/app.js` 中 `OFFLINE_ALERT_MINUTES`）无数据 → 写 `alerts`（`notified:false`，由 alertChecker 负责推送）

---

### 接口 3：获取轨迹（GET /history）

```
GET .../upload/history[?since=timestamp]
```

| 参数 | 必填 | 说明 |
|---|:--:|---|
| `since` | 否 | 增量查询：只返回该时间之后的数据（默认24小时内，最多1000条） |

读取 `trochoid` 集合，时间升序。返回含 `gcj02_lat`/`gcj02_lng`。

---

### 接口 4：获取历史状态（GET /statusHistory）

```
GET .../upload/statusHistory?hours=24|168|720
```

读取 `can_history` 集合。返回精简字段：`time` / `voltage` / `fuel` / `temperature`。

---

### 接口 5：查询未读告警（GET /alerts）

```
GET .../upload/alerts?deviceId=car001&since=0
```

**返回：**
```json
{
  "code": 0,
  "data": {
    "unreadCount": 2,
    "alerts": [ { "_id", "deviceId", "type", "message", "time", "read", "detail" } ]
  }
}
```

---

### 接口 6：标记告警已读（POST /alerts/read）

```
POST .../upload/alerts/read
Body: { "ids": ["告警_id1", "告警_id2"] }
```

---

## 🗂️ 数据库集合

### `device`（最新状态，单文档）

| 字段 | 说明 |
|---|---|
| deviceId | 设备ID |
| lat / lng / gcj02_lat / gcj02_lng | WGS84 + GCJ02 坐标 |
| locationValid | 位置有效性 |
| correctedAltitude | 校准后海拔 |
| 全部上传字段 | 见「终端上传字段定义」 |
| lastDataTime | 最后数据时间（离线检测） |
| time | 数据时间戳 |

### `can_history`（完整历史，追加）

同 `device` 全字段，每次上传追加一条。

### `trochoid`（轨迹，30秒采样）

| 字段 | 说明 |
|---|---|
| deviceId / lat / lng | 坐标（WGS84） |
| gcj02_lat / gcj02_lng | GCJ02 坐标 |
| speed / time | 速度 / 时间戳 |

### `alerts`（告警记录）

| 字段 | 类型 | 说明 |
|---|---|---|
| deviceId | String | 设备ID |
| type | String | `illegal_movement`（非法移动）/ `abnormal_offline`（异常离线） |
| message | String | 告警描述 |
| time | Number | 告警时间戳 |
| read | Boolean | 是否已读 |
| detail | Object | 详情（移动距离 / 离线小时数等） |

### `subscribers`（订阅用户）

| 字段 | 类型 | 说明 |
|---|---|---|
| openid | String | 用户 openid |
| createTime / lastRegisterTime | Number | 注册/更新时间 |

---

## 🔔 告警推送系统

### 告警类型与触发

| 类型 | 条件 | 检测位置 | 频率 |
|---|---|---|---|
| `illegal_movement` | offline 状态位置变化 >100m | `upload` POST | 每次终端上传 |
| `abnormal_offline` | 超过阈值无数据（默认 10 分钟，`alertChecker` 的 `DEFAULT_OFFLINE_MINUTES`，也可在 device 文档加 `offlineAlertMinutes` 按设备配置） | `upload` GET /latest + `alertChecker` 定时器 | 15秒轮询 + 20分钟定时 |

### 推送链路

```
告警产生 → alerts 集合（notified:false 待推送）
  ├─ 微信订阅消息：alertChecker（每20分钟）查「未推送」告警
  │    → cloud.openapi.subscribeMessage.send() 推给所有 subscribers
  │    → 成功置 notified:true（本次离线不再重复推）
  │    → 失败保留 notified:false（下次定时器重试，如 43101 额度用完）
  │    → 无订阅用户时不标记，等有新用户订阅后补推
  └─ 应用内提示：app.js 每15秒 fetchAlerts()
       → 首页红点角标 + wx.showModal 弹窗
       → 点"我知道了" → markAlertsRead → 红点消失
```

**恢复上线自动复位：** 终端恢复上传（POST /upload）时，自动把该设备未读的 `abnormal_offline` 告警置为已读，使下次离线可再次触发告警与推送。

### 订阅消息模板

| 项 | 值 |
|----|----|
| 模板ID | `YOUR_TEMPLATE_ID` |
| 异常名称 | `{{thing2.DATA}}` |
| 车牌号 | `{{car_number6.DATA}}`（当前占位 "car001"，在 notify/alertChecker 顶部 PLATE_NUMBER 修改） |

### 订阅授权流程

```
打开小程序（首页 onShow）→ 检测本地 subscribed 记录
  ├─ 从未授权 → 弹窗"是否开启车辆告警推送？" → 点"开启"
  │              → 微信授权卡片 → 允许 → 记录授权时间/次数 + 注册 openid
  └─ 距上次授权 ≥7 天 → 弹窗"重新授权通知"（额度可能已用完）
        → 点"开启" → 微信授权卡片 → 允许 → 更新授权时间/次数
```

> ⚠️ **一次性订阅限制**：每授权一次仅可接收 1 条订阅消息，发送后额度即耗尽。
> 前端 `subscribed` 本地缓存已改为对象 `{ count, lastTime }`，不再永久标记"已开启"；
> 首页可随时点击"🔔 推送通知 → 点击授权（1次=1条）"补充分额度。

---

## 🎨 前端显示逻辑

### 车辆状态映射

| carState | 图标 | 文本 | 颜色 |
|---|---|---|---|
| online | online.png | 车辆在线 | 绿 #52c41a |
| offline | offline.png | 车辆已下线 | 灰 #999 |
| lowpower | lowpower.png | 电瓶电压低 | 黄 #faad14 |
| waiting | waiting.png | 车辆待机 | 蓝 #1677ff |

### 定位精度圈（HDOP）

地图 marker 外围半透明蓝色圆，半径 = HDOP × 5 米（范围 10~500m）。

| HDOP | 半径 | 定位质量 |
|---|---|---|
| 1 | 10m | 高精度 |
| 3 | 15m | 良好 |
| 5 | 25m | 一般 |
| 10 | 50m | 较差 |

### 智能时间显示

`formatRelativeTime()`：今天→`时:分`，昨天→`昨天 时:分`，前天→`前天 时:分`，更早→`月-日 时:分`

---

## 🔄 全局轮询机制（app.js）

```
startGlobalPolling():
  · 立即 fetchCarData() + fetchAlerts()
  · 每 15 秒重复
  · onHide 停止 / onShow 恢复
```

- `globalData.carInfo`：最新车辆数据缓存
- `globalData.unreadAlertCount / alerts`：未读告警缓存
- `onCarDataReady(callback)`：首次数据就绪通知
- `onAlertChange(callback)`：告警变化通知
- `markAlertsRead(ids)`：标记已读

---

## 💰 云资源优化策略

| 优化项 | 说明 |
|---|---|
| 全局轮询 15 秒 | app.js 统一拉取，页面读取缓存不再各自请求 |
| 后台暂停轮询 | onHide 停止 / onShow 恢复 |
| 历史数据缓存 | can_history 1小时缓存；轨迹增量合并 |
| 正常离线判断 | online 60秒 / waiting 180秒 无数据自动 offline |
| 告警去重 | 同设备 `notified:true` 且未读 → 不再重复推送；推送失败保留 `notified:false` 定时重试 |

---

## 📄 云函数部署说明

| 云函数 | 说明 | 部署方式 |
|---|---|---|
| `upload` | HTTP 主后端 | 上传并部署：云端安装依赖 |
| `alertChecker` | 定时检测 + 推送（每20分钟，config.json 配置触发器） | 上传并部署：云端安装依赖 |
| `notify` | 订阅消息注册/发送 | 上传并部署：云端安装依赖 |

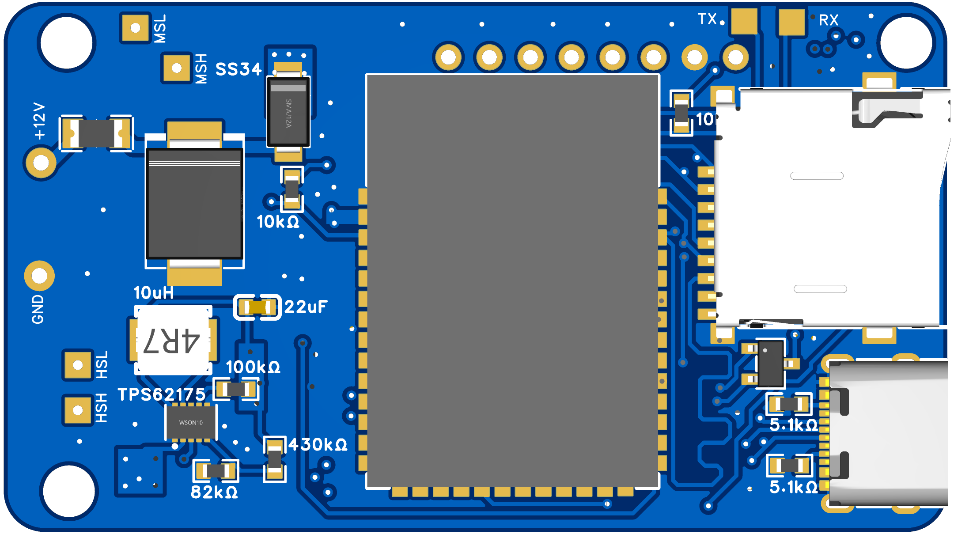
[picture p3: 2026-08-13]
hardware/images/3D_PCB1_TopLayer.png

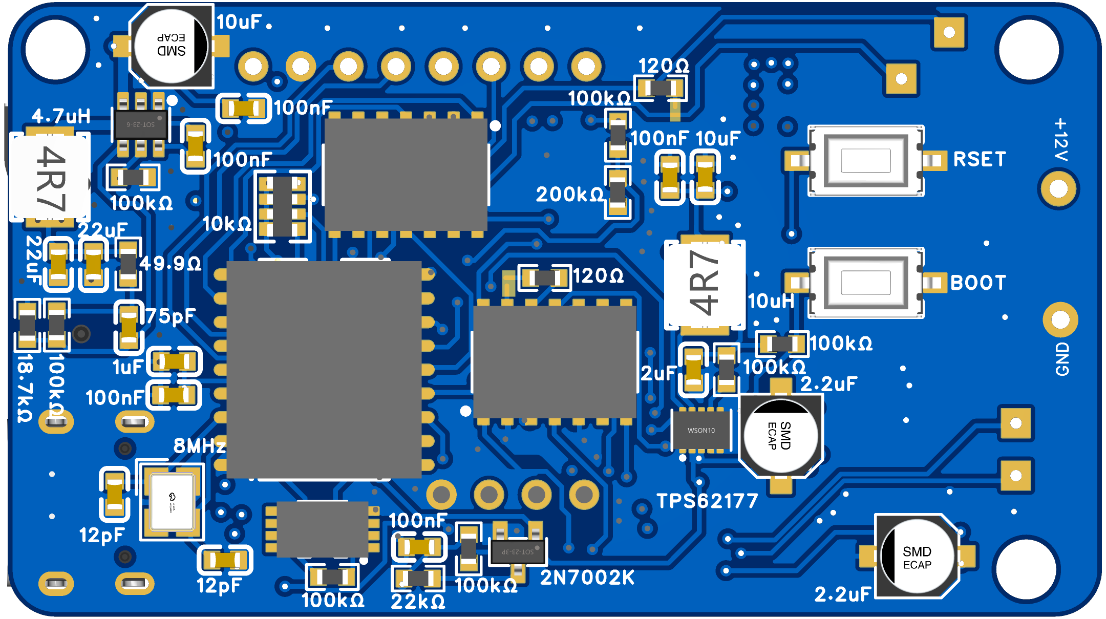
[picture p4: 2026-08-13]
hardware/images/3D_PCB1_BottomLayer.png

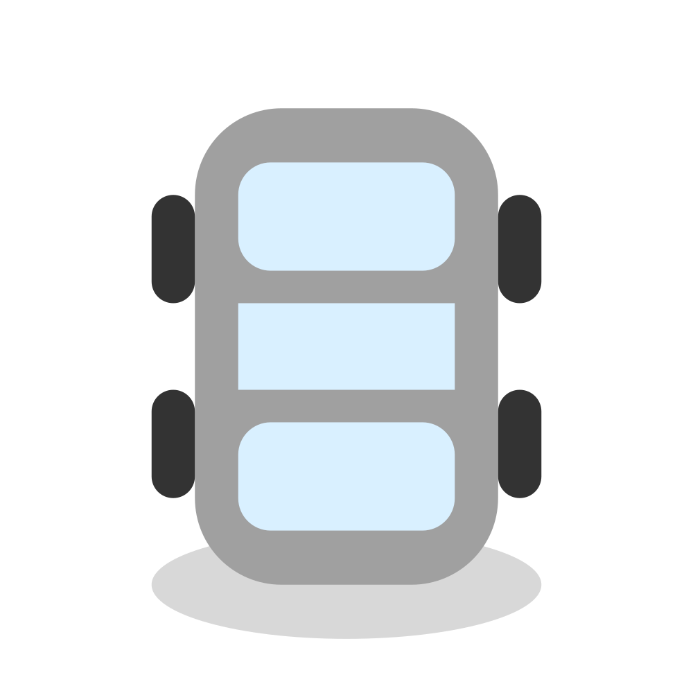
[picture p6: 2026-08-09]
miniprogram/miniprogram/images/car_state/offline.png

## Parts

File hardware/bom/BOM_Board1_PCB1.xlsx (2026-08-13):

No. | Quantity | Comment | Designator | Footprint | Value
1 | 2 | 2.2uF | C1,C14 | CAP-SMD_BD4.0-L4.3-W4.3-LS5.0-FD | 2.2uF
2 | 5 | 100nF | C2,C3,C17,C19,C21 | C0603 | 100nF
3 | 4 | 22uF | C4,C5,C8,C11 | C0603 | 22uF
4 | 1 | 75pF | C6 | C0603 | 75pF
5 | 1 | 10uF | C9 | CAP-SMD_BD4.0-L4.3-W4.3-LS5.0-FD | 10uF
6 | 2 | 12pF | C12,C13 | C0603 | 12pF
7 | 1 | 10uF | C18 | C0603 | 10uF
8 | 1 | 1uF | C20 | C0603 | 1uF
9 | 1 | TF-01A | CARD1 | TF-SMD_TF-01A
10 | 1 | SMCJ16A-E3/57T | D1 | SMC_L6.9-W5.9-LS7.9-RD
11 | 1 | SS34 | D2 | SMA_L4.3-W2.6-LS5.0-FD
12 | 1 | SMD1206-60-30 | F1 | F1206
13 | 1 | 4.7uH | L1 | IND-SMD_L4.6-W4.1-A | 4.7uH
14 | 2 | 10uH | L2,L3 | IND-SMD_L4.6-W4.1-A | 10uH
15 | 1 | AO3407A | Q1 | SOT-23-3_L2.9-W1.6-P1.90-LS2.8-BR
16 | 1 | 49.9Ω | R1 | R0603 | 49.9Ω
17 | 8 | 100kΩ | R2,R5,R8,R10,R12,R13,R15,R20 | R0603 | 100kΩ
18 | 1 | 18.7kΩ | R3 | R0603 | 18.7kΩ
19 | 2 | 10kΩ | R4,R14 | R0603 | 10kΩ
20 | 2 | 5.1kΩ | R6,R7 | R0603 | 5.1kΩ
21 | 1 | 200kΩ | R9 | R0603 | 200kΩ
22 | 1 | 22kΩ | R11 | R0603 | 22kΩ
23 | 2 | 120Ω | R16,R17 | R0603 | 120Ω
24 | 1 | 430kΩ | R18 | R0603 | 430kΩ
25 | 1 | 82kΩ | R19 | R0603 | 82kΩ
26 | 1 | 10kΩ | RN1 | RES-ARRAY-SMD_0603-8P-L3.2-W1.6-BL | 10kΩ
27 | 2 | TS-1101-C-W | SW1,SW2 | SW-SMD_L6.0-W3.3-LS8.0_TS-1101-C-W
28 | 1 | TPS54302 | U1 | SOT-23-6_L2.9-W1.6-P0.95-LS2.8-BL
29 | 1 | TPS62177 | U2 | WSON-10_L3.0-W2.0-P0.50-BL-EP
30 | 1 | ESP32-S3-WROOM-1-N16R8 | U3 | WIRELM-SMD_ESP32-S3-WROOM-1 | 2.4GHz
31 | 2 | SIT1145 | U4,U5 | SOP-14_L8.7-W3.9-P1.27-LS6.0-BL
32 | 1 | MCP2515 | U6 | SOIC-18_L11.6-W7.5-P1.27-LS10.3-BL
33 | 1 | DS18B20 | U8 | MSOP-8_L3.0-W3.0-P0.65-LS4.9-BL
34 | 1 | 2N7002K | U10 | SOT-23-3_L2.9-W1.3-P0.95-LS2.4-BR
35 | 1 | M100MG-C2 | U11 | M100MG-C2物联网模块
36 | 1 | TPS62175 | U12 | WSON-10_L3.0-W2.0-P0.50-BL-EP
37 | 1 | TYPE-C 16PIN 2MD(073) | USB1 | USB-C-SMD_TYPE-C-16PIN-2MD-073
38 | 1 | 8MHz | X1 | CRYSTAL-SMD_4P-L3.2-W2.5-BL | 8MHz

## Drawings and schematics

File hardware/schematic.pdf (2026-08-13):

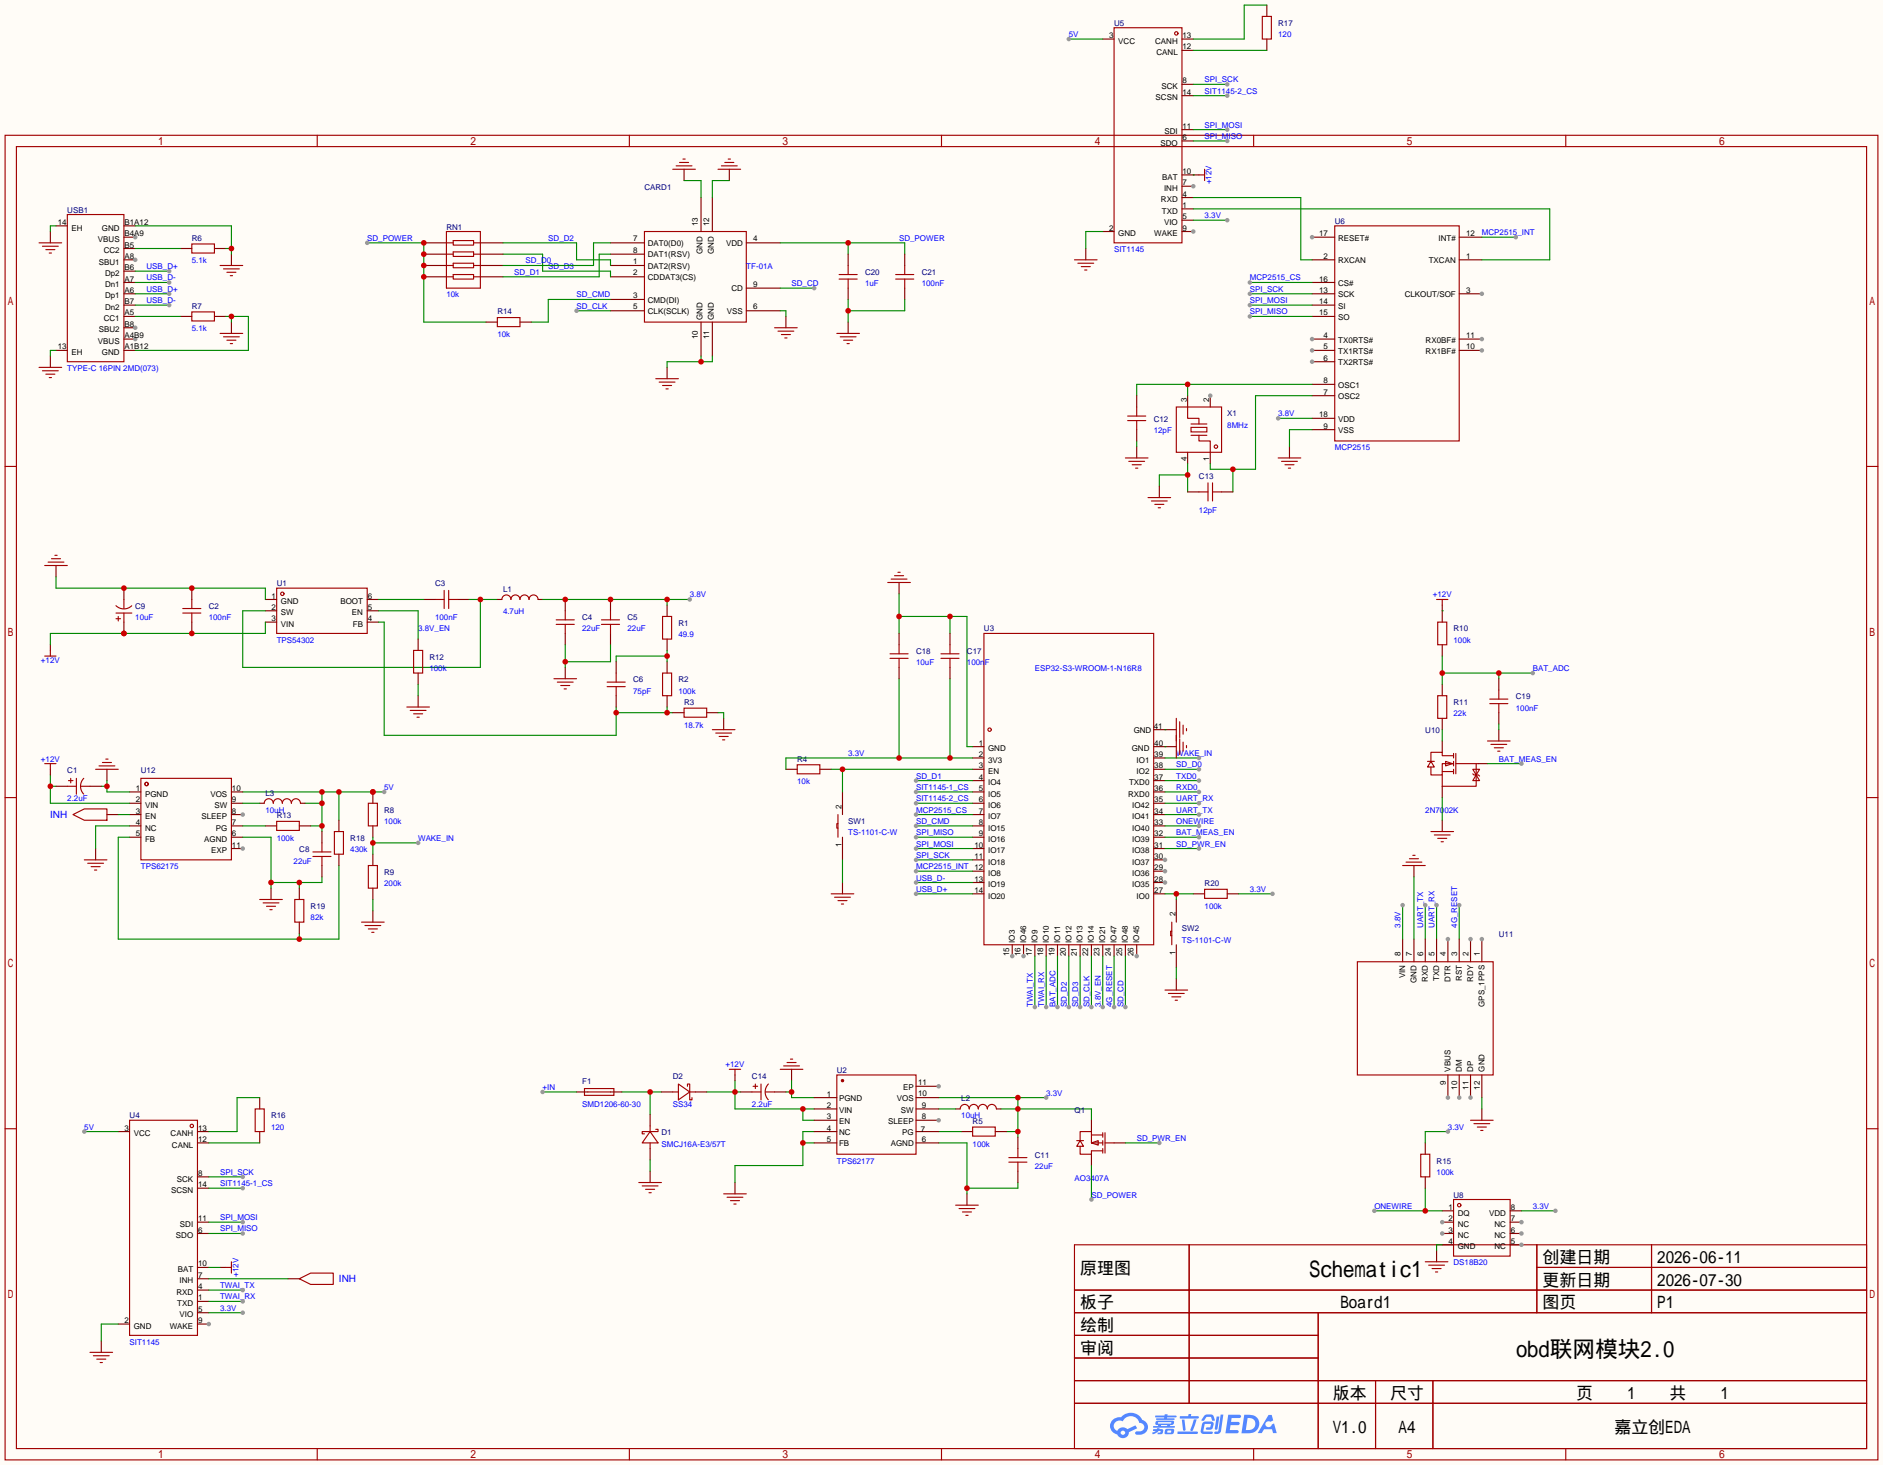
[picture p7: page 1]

USB1
GND A1B12 VBUS A4B9 SBU2 B8 CC1 A5 Dn2 B7 Dp1 A6 Dn1 A7 Dp2 B6 SBU1 A8 CC2 B5 VBUS B4A9 GND B1A12 EH 14

原理图 | Schematic1 | | 创建日期 | 2026-06-11

更新日期 | 2026-07-30

板子 | Board1 | | 图页 | P1
绘制 | | obd联网模块2.0
审阅

V1.0 | A4 | 嘉立创EDA

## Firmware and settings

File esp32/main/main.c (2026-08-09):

/**
 * @file main.c
 * @brief 系统主入口 — ESP32-S3 车载终端
 *
 * 唤醒类型判断:
 *   - 上电/GPIO 唤醒 → 全初始化
 *   - 定时器自主唤醒 → GPS 轮询
 *
 * GPS 轮询逻辑 (进入 sleep 前设置 3 分钟定时器):
 *   light sleep 阶段 (前 10 分钟, 约 3 次):
 *     → GPS 轮询 2 分钟 → 回到 light sleep (GPIO21=高)
 *   deep sleep 阶段 (10 分钟后):
 *     → GPIO21=高 → GPS 轮询 2 分钟 → GPIO21=低 → deep sleep
 *   GPIO1 外部唤醒 → 全初始化
 */

#include <stdio.h>
#include <inttypes.h>
#include <string.h>
#include "sdkconfig.h"
#include "freertos/FreeRTOS.h"
#include "freertos/task.h"
#include "freertos/semphr.h"
#include "esp_log.h"
#include "esp_timer.h"
#include "esp_psram.h"
#include "esp_sleep.h"
#include "driver/gpio.h"
#include "driver/uart.h"
#include "driver/twai.h"
#include "board_config.h"
#include "spi_bus.h"
#include "sit1145.h"
#include "mcp2515.h"
#include "twai_driver.h"
#include "sd_card.h"
#include "sd_logger.h"
#include "can_buffer.h"
#include "can_parser.h"
#include "modem_4g.h"
#include "ds18b20.h"
#include "battery.h"
#include "power_manager.h"
#include "gps_poller.h"

static const char *TAG = "MAIN";

/* RTC 内存变量 (跨 deep sleep 保留) */
RTC_DATA_ATTR static uint8_t s_auto_wake_flag = 0;  /* 1=自主唤醒标志 */
RTC_DATA_ATTR static uint8_t s_wake_count = 0;      /* light sleep 定时器唤醒计数 (>=3 进 deep) */

/* PSRAM 双缓冲区 */
static can_buffer_ctx_t s_mcp_buf;
static can_buffer_ctx_t s_twai_buf;
static SemaphoreHandle_t s_sd_sem;

/* 任务句柄 */
static TaskHandle_t s_mcp2515_task_handle = NULL;
static TaskHandle_t s_twai_task_handle = NULL;
static TaskHandle_t s_sd_write_task_handle = NULL;

/* SPI 设备句柄 */
static spi_device_handle_t h_sit1, h_sit2, h_mcp;

/* 前向声明 */
static void power_manager_enter_auto_sleep(void);
static void wake_reinit(void);

/* ====================================================================== */
/*                          外设初始化                                     */
/* ====================================================================== */

static void init_all(void)
{
    ESP_LOGI(TAG, "===== 全初始化 =====");

    strcpy(g_state.deviceId, "car001");
    strcpy(g_state.carState, "online");

    gpio_set_direction(PIN_PWR_3V8_EN, GPIO_MODE_OUTPUT);
    gpio_set_level(PIN_PWR_3V8_EN, 1);
    vTaskDelay(pdMS_TO_TICKS(50));

    ESP_ERROR_CHECK(spi_bus_init_board(PIN_SPI_MOSI, PIN_SPI_MISO, PIN_SPI_SCK));
    ESP_ERROR_CHECK(spi_bus_add_device_custom(PIN_SIT1_CS, 1 * 1000 * 1000, 1, &h_sit1));
    spi_bus_set_device_name(h_sit1, "SIT1145-1");
    ESP_ERROR_CHECK(spi_bus_add_device_custom(PIN_SIT2_CS, 1 * 1000 * 1000, 1, &h_sit2));
    spi_bus_set_device_name(h_sit2, "SIT1145-2");
    ESP_ERROR_CHECK(spi_bus_add_device_custom(PIN_MCP2515_CS, 8 * 1000 * 1000, 0, &h_mcp));
    spi_bus_set_device_name(h_mcp, "MCP2515");

    g_state.sit1145_1_init = (sit1145_init(SIT1145_DEV_1, h_sit1) == ESP_OK) ? 1 : 0;
    g_state.sit1145_2_init = (sit1145_init(SIT1145_DEV_2, h_sit2) == ESP_OK) ? 1 : 0;
    sit1145_verify_chip_id(SIT1145_DEV_1);
    sit1145_verify_chip_id(SIT1145_DEV_2);
    g_state.mcp2515_init = (mcp2515_init(h_mcp, PIN_MCP2515_INT) == ESP_OK) ? 1 : 0;

    esp_err_t twai_ret = twai_driver_init(PIN_TWAI_TX, PIN_TWAI_RX);
    if (twai_ret == ESP_OK) twai_driver_start();
    else ESP_LOGW(TAG, "TWAI 跳过");

    esp_err_t sd_ret = sd_card_init(PIN_SD_PWR_EN, PIN_SD_CD);
    if (sd_ret == ESP_OK) {
        sd_logger_init("sit1145");
        sd_logger_init("mcp2515");
    } else ESP_LOGW(TAG, "SD 卡失败");

    size_t psram_size = esp_psram_get_size();
    if (psram_size > 0) ESP_LOGI(TAG, "PSRAM: %zu bytes", psram_size);
    else ESP_LOGW(TAG, "PSRAM 不可用");

    can_buffer_init(&s_mcp_buf, "mcp2515");
    can_buffer_init(&s_twai_buf, "sit1145");
    s_sd_sem = xSemaphoreCreateCounting(10, 0);
    can_buffer_set_shared_sem(&s_mcp_buf, s_sd_sem);
    can_buffer_set_shared_sem(&s_twai_buf, s_sd_sem);

    esp_err_t ret4g = modem_4g_init(PIN_4G_TX, PIN_4G_RX, PIN_4G_RESET, 115200);
    if (ret4g == ESP_OK) {
        char resp[128] = {0};
        modem_4g_send_at("AT\r\n", resp, sizeof(resp), 1000);
        ESP_LOGI(TAG, "4G AT: %s", resp);
    }

    ds18b20_init(PIN_DS18B20);
    if (ds18b20_is_present()) ESP_LOGI(TAG, "DS18B20 ✓");

    esp_err_t bat_ret = battery_adc_init(PIN_BAT_ADC, PIN_BAT_MEAS_EN);
    if (bat_ret != ESP_OK) ESP_LOGW(TAG, "ADC 跳过");

    ESP_LOGI(TAG, "===== 全初始化完成 =====");
}

/* ====================================================================== */
/*  外设重新初始化 (light sleep GPIO 唤醒后)                                */
/* ====================================================================== */

static void wake_reinit(void)
{
    ESP_LOGI(TAG, "===== [LIGHT SLEEP 唤醒] 重新初始化外设 =====");

    /* 步骤 1/5: 重新添加 SPI 设备 */
    ESP_LOGI(TAG, "[1/5] 重新添加 SPI 设备...");
    spi_bus_del_device(h_sit1);
    spi_bus_del_device(h_sit2);
    spi_bus_del_device(h_mcp);
    ESP_ERROR_CHECK(spi_bus_add_device_custom(PIN_SIT1_CS, 1 * 1000 * 1000, 1, &h_sit1));
    spi_bus_set_device_name(h_sit1, "SIT1145-1");
    ESP_ERROR_CHECK(spi_bus_add_device_custom(PIN_SIT2_CS, 1 * 1000 * 1000, 1, &h_sit2));
    spi_bus_set_device_name(h_sit2, "SIT1145-2");
    ESP_ERROR_CHECK(spi_bus_add_device_custom(PIN_MCP2515_CS, 8 * 1000 * 1000, 0, &h_mcp));
    spi_bus_set_device_name(h_mcp, "MCP2515");

    /* 步骤 2/5: 重新初始化 SIT1145 */
    ESP_LOGI(TAG, "[2/5] 初始化 SIT1145...");
    sit1145_init(SIT1145_DEV_1, h_sit1);
    sit1145_init(SIT1145_DEV_2, h_sit2);

    /* 步骤 3/5: 重新初始化 MCP2515 */
    ESP_LOGI(TAG, "[3/5] 初始化 MCP2515...");
    mcp2515_init(h_mcp, PIN_MCP2515_INT);

    /* 步骤 4/5: 重新挂载 SD 卡 */
    ESP_LOGI(TAG, "[4/5] 挂载 SD 卡...");
    esp_err_t sd_ret = sd_card_init(PIN_SD_PWR_EN, PIN_SD_CD);
    if (sd_ret == ESP_OK) {
        sd_logger_init("sit1145");
        sd_logger_init("mcp2515");
    }

    /* 重新启动 TWAI (进入 standby 前仅 stop, 仍 installed, 直接 start 即可) */
    twai_driver_start();

    /* 步骤 5/5: 注册句柄 */
    ESP_LOGI(TAG, "[5/5] 注册句柄...");
    power_manager_register_spi_handles(h_sit1, h_sit2, h_mcp);
    mcp2515_register_task(s_mcp2515_task_handle);

    ESP_LOGI(TAG, "===== 外设重新初始化完成 =====");
}

/* ====================================================================== */
/*  GPS 轮询 + 睡眠循环                                                    */
/* ====================================================================== */

static void power_manager_enter_auto_sleep(void)
{
    ESP_LOGI(TAG, "--- GPS 轮询完成, 准备再次进入 sleep ---");

    if (s_wake_count >= 3) {
        gpio_set_level(PIN_PWR_3V8_EN, 0);
        ESP_LOGI(TAG, "GPIO21=低, 进入 deep sleep");
        s_wake_count = 0;
        power_manager_set_mode(POWER_MODE_SLEEP);
        power_manager_enter_sleep();
    } else {
        ESP_LOGI(TAG, "GPIO21=高, 继续 light sleep (wake_count=%d)", s_wake_count);
        power_manager_set_mode(POWER_MODE_STANDBY);
        power_manager_enter_standby();
    }
}

/* ====================================================================== */
/*  任务                                                                   */
/* ====================================================================== */

static void mcp2515_task(void *arg)
{
    s_mcp2515_task_handle = xTaskGetCurrentTaskHandle();
    mcp2515_register_task(s_mcp2515_task_handle);
    ESP_LOGI(TAG, "[Core0] MCP2515 任务启动");

    while (1) {
        ulTaskNotifyTake(pdTRUE, portMAX_DELAY);
        if (power_manager_get_mode() != POWER_MODE_NORMAL) continue;
        while (mcp2515_has_interrupt() && power_manager_get_mode() == POWER_MODE_NORMAL) {
            mcp2515_frame_t frame;
            if (mcp2515_receive_frame(&frame) == ESP_OK) {
                can_buffer_write_csv(&s_mcp_buf, frame.id, frame.dlc,
                                     frame.data, frame.is_extended, frame.is_rtr);
                can_parser_process(frame.id, frame.data, frame.dlc);
                power_manager_mark_can_activity();
            } else break;
        }
    }
}

static void twai_task(void *arg)
{
    s_twai_task_handle = xTaskGetCurrentTaskHandle();
    ESP_LOGI(TAG, "[Core1] TWAI 任务启动");
    twai_frame_t frame;

    while (1) {
        bool has_data = twai_driver_wait_rx(1000);
        if (power_manager_get_mode() != POWER_MODE_NORMAL) continue;
        if (has_data) {
            while (twai_driver_receive(&frame, 0) == ESP_OK) {
                can_buffer_write_csv(&s_twai_buf, frame.id, frame.dlc,
                                     frame.data, frame.is_extended, frame.is_rtr);
                can_parser_process(frame.id, frame.data, frame.dlc);
                power_manager_mark_can_activity();
            }
        }
    }
}

static void sd_write_task(void *arg)
{
    s_sd_write_task_handle = xTaskGetCurrentTaskHandle();
    ESP_LOGI(TAG, "SD 写入任务启动");

    while (1) {
        xSemaphoreTake(s_sd_sem, portMAX_DELAY);
        char *data = NULL; uint32_t size = 0;
        if (can_buffer_get_full(&s_mcp_buf, &data, &size)) {
            sd_logger_write("mcp2515", data, size);
            can_buffer_release_full(&s_mcp_buf);
        }
        if (can_buffer_get_full(&s_twai_buf, &data, &size)) {
            sd_logger_write("sit1145", data, size);
            can_buffer_release_full(&s_twai_buf);
        }
    }
}

static void sensor_task(void *arg)
{
    int counter = 0;
    ESP_LOGI(TAG, "传感器任务启动");

    while (1) {
        counter++;
        vTaskDelay(pdMS_TO_TICKS(1000));

        power_manager_tick(esp_timer_get_time() / 1000);

        if (power_manager_should_standby()) {
            ESP_LOGI(TAG, "===== 空闲超时, 进入待机 =====");

        vTaskSuspend(s_mcp2515_task_handle);
            vTaskSuspend(s_twai_task_handle);
            vTaskSuspend(s_sd_write_task_handle);
            /* TWAI 驱动保持 installed 状态 (仅停止通信), 避免 light sleep 唤醒后硬件残留中断 */
            twai_driver_stop();

            /* 卸载 4G 模块的 UART1 驱动 (GPS 轮询会重新安装) */
            uart_driver_delete(UART_NUM_1);

            char *data = NULL; uint32_t size = 0;
            if (can_buffer_get_full(&s_mcp_buf, &data, &size)) {
                sd_logger_write("mcp2515", data, size);
                can_buffer_release_full(&s_mcp_buf);
            }
            if (can_buffer_get_full(&s_twai_buf, &data, &size)) {
                sd_logger_write("sit1145", data, size);
                can_buffer_release_full(&s_twai_buf);
            }
            sd_card_deinit();

            /* 清零计数, 进入 light sleep 阶段 */
            s_auto_wake_flag = 1;
            s_wake_count = 0;

            /* GPIO21 保持高电平, 进入 light sleep */
            gpio_set_direction(PIN_PWR_3V8_EN, GPIO_MODE_OUTPUT);
            gpio_set_level(PIN_PWR_3V8_EN, 1);
            power_manager_set_mode(POWER_MODE_STANDBY);
            power_manager_enter_standby();

            /* 从 light sleep 唤醒 */
            if (power_manager_is_auto_wake()) {
                /* 定时器唤醒 → GPS 轮询 */
                ESP_LOGI(TAG, "定时器唤醒 (wake_count=%d/3)", s_wake_count);

                gps_poller_uart_init();
                gps_poller_run_cycle();
                gps_poller_uart_deinit();

                s_wake_count++;
                s_auto_wake_flag = 1;

                if (s_wake_count >= 3) {
                    /* 达到 3 次 → 进 deep sleep, GPIO21=低 */
                    gpio_set_level(PIN_PWR_3V8_EN, 0);
                    ESP_LOGI(TAG, "wake_count=%d, 进入 deep sleep", s_wake_count);
                    s_wake_count = 0;
                    power_manager_set_mode(POWER_MODE_SLEEP);
                    power_manager_enter_sleep();
                } else {
                    /* 继续 light sleep, GPIO21=高 */
                    ESP_LOGI(TAG, "wake_count=%d, 继续 light sleep", s_wake_count);
                    power_manager_set_mode(POWER_MODE_STANDBY);
                    power_manager_enter_standby();
                }
                /* power_manager_enter_sleep/standby 不会返回(会再次 sleep),
                   但如果从 deep sleep 回来则重启, 从 light sleep 回来则回到这里 */
                /* 重新进来后再次判断唤醒类型 */
            } else {
                /* GPIO 唤醒 → 全初始化 */
                s_auto_wake_flag = 0;
                wake_reinit();
                vTaskResume(s_mcp2515_task_handle);
                vTaskResume(s_twai_task_handle);
                vTaskResume(s_sd_write_task_handle);
                power_manager_set_mode(POWER_MODE_NORMAL);
                power_manager_mark_can_activity();
                ESP_LOGI(TAG, "===== 外部唤醒, 恢复正常 =====");
            }
        }

        /* SD 卡热插拔检测 (CD 中断触发后检查) */
        if (sd_card_cd_changed()) {
            if (sd_card_get_cd_level() == 0) {
                ESP_LOGI(TAG, "SD 卡插入, 尝试挂载...");
                if (sd_card_init(PIN_SD_PWR_EN, PIN_SD_CD) == ESP_OK) {
                    sd_logger_init("sit1145");
                    sd_logger_init("mcp2515");
                    ESP_LOGI(TAG, "SD 卡热插挂载成功");
                }
            } else {
                ESP_LOGI(TAG, "SD 卡拔出, 卸载...");
                sd_card_deinit();
            }
        }

        if (counter % 10 == 0) {
            int32_t temp = 0;
            if (ds18b20_read_temp(&temp) == ESP_OK)
                g_state.temperature = (float)temp / 1000.0f;
            uint32_t bat_mv = 0; uint8_t bat_pct = 0;
            if (battery_read_mv(&bat_mv) == ESP_OK) {
                battery_read_percent(&bat_pct);
                g_state.voltage = (float)bat_mv / 1000.0f;
                g_state.fuel = bat_pct;
            }
            ESP_LOGI(TAG, "[STATE] %s V=%.2f fuel=%d temp=%.1f idle=%llu",
                     g_state.carState, g_state.voltage, g_state.fuel,
                     g_state.temperature,
                     (unsigned long long)power_manager_get_idle_ms());
        }
    }
}

/* ====================================================================== */
/*  app_main                                                               */
/* ====================================================================== */

void app_main(void)
{
    esp_sleep_wakeup_cause_t cause = esp_sleep_get_wakeup_cause();

    if (cause == ESP_SLEEP_WAKEUP_TIMER && s_auto_wake_flag) {
        /* ===== 定时器自主唤醒: GPS 轮询 ===== */
        ESP_LOGI(TAG, "自主唤醒 (wake_count=%d/3)", s_wake_count);

        gps_poller_uart_init();
        gps_poller_run_cycle();
        gps_poller_uart_deinit();

        s_wake_count++;
        s_auto_wake_flag = 1;

        if (s_wake_count >= 3) {
            gpio_set_level(PIN_PWR_3V8_EN, 0);
            ESP_LOGI(TAG, "wake_count=%d, 进入 deep sleep", s_wake_count);
            s_wake_count = 0;
            power_manager_set_mode(POWER_MODE_SLEEP);
            power_manager_enter_sleep();
        } else {
            ESP_LOGI(TAG, "wake_count=%d, 继续 light sleep", s_wake_count);
            power_manager_set_mode(POWER_MODE_STANDBY);
            power_manager_enter_standby();
        }
        return;
    }

    /* ===== 上电 或 GPIO 唤醒 (deep sleep 恢复也走此路径) ===== */
    s_auto_wake_flag = 0;
    s_wake_count = 0;
    if (cause == ESP_SLEEP_WAKEUP_EXT1) {
        ESP_LOGI(TAG, "[DEEP SLEEP 唤醒] GPIO1 外部唤醒, 全初始化");
    } else {
        ESP_LOGI(TAG, "上电复位: 全初始化");
    }

    init_all();
    power_manager_init();
    power_manager_register_spi_handles(h_sit1, h_sit2, h_mcp);

    UBaseType_t prio_highest = configMAX_PRIORITIES - 1;
    xTaskCreatePinnedToCore(mcp2515_task, "mcp2515", 3072, NULL, prio_highest, NULL, 0);
    xTaskCreatePinnedToCore(twai_task,    "twai",    3072, NULL, prio_highest, NULL, 1);
    xTaskCreatePinnedToCore(sd_write_task,"sd_write",4096, NULL, 1,            NULL, 1);
    xTaskCreatePinnedToCore(sensor_task,  "sensor",  4096, NULL, 5,            NULL, 1);

    vTaskDelete(NULL);
}

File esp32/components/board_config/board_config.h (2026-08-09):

/**
 * @file board_config.h
 * @brief 板级引脚定义 — ESP32-S3-WROOM-1-N8R2 车载终端
 *
 * 引脚分配说明:
 *   - SPI 总线 (SPI2_HOST) 共享: SIT1145-1(CS=5)、SIT1145-2(CS=6)、MCP2515(CS=7)
 *   - TWAI (内置 CAN): TX=GPIO10, RX=GPIO9
 *   - SD 卡: SDMMC 4-bit 模式, 电源使能 GPIO38
 *   - 4G 模块: UART1, TX=GPIO41, RX=GPIO42, 复位=GPIO47
 *   - DS18B20: 单总线 GPIO40
 *   - 电池 ADC: GPIO11 (ADC2), 测量使能 GPIO39
 */

#ifndef BOARD_CONFIG_H
#define BOARD_CONFIG_H

#ifdef __cplusplus
extern "C" {
#endif

/* ====================================================================== */
/*   USB Serial / JTAG  (内置, 仅用于固件烧录和调试)                       */
/* ====================================================================== */
#define PIN_USB_DN       19         /* USB D- (USB Serial/JTAG 内置)     */
#define PIN_USB_DP       20         /* USB D+ (USB Serial/JTAG 内置)     */

/* ====================================================================== */
/*   SD 卡 — SDMMC 4-bit 模式                                             */
/* ====================================================================== */
#define PIN_SD_CLK       14         /* SDMMC 时钟                        */
#define PIN_SD_CMD       15         /* SDMMC 命令线                      */
#define PIN_SD_D0         2         /* SDMMC 数据线 D0                   */
#define PIN_SD_D1         4         /* SDMMC 数据线 D1                   */
#define PIN_SD_D2        12         /* SDMMC 数据线 D2                   */
#define PIN_SD_D3        13         /* SDMMC 数据线 D3                   */
#define PIN_SD_PWR_EN    38         /* SD 卡电源使能 (高电平开启)        */
#define PIN_SD_CD        48         /* SD 卡检测引脚 (低电平=有卡)       */

/* ====================================================================== */
/*   SPI 总线 — SPI2_HOST, 共享给 3 个设备                                */
/* ====================================================================== */
#define PIN_SPI_MISO     16         /* SPI 主入从出                       */
#define PIN_SPI_MOSI     17         /* SPI 主出从入                       */
#define PIN_SPI_SCK      18         /* SPI 时钟                          */

/* ====================================================================== */
/*   SIT1145 CAN 收发器 (SPI 接口)                                        */
/* ====================================================================== */
#define PIN_SIT1_CS       5         /* SIT1145-1 片选 (TWAI 路)          */
#define PIN_SIT2_CS       6         /* SIT1145-2 片选 (MCP2515 路)       */

/* ====================================================================== */
/*   MCP2515 CAN 控制器 (SPI 接口)                                        */
/* ====================================================================== */
#define PIN_MCP2515_CS    7         /* MCP2515 片选                      */
#define PIN_MCP2515_INT   8         /* MCP2515 中断输入 (低电平有效)     */

/* ====================================================================== */
/*   TWAI — ESP32-S3 内置 CAN 控制器                                      */
/* ====================================================================== */
#define PIN_TWAI_TX      10         /* TWAI 发送 (连接 SIT1145-1 TXD)    */
#define PIN_TWAI_RX       9         /* TWAI 接收 (连接 SIT1145-1 RXD)    */

/* ====================================================================== */
/*   4G 模块 — UART 通信                                                  */
/* ====================================================================== */
#define PIN_4G_TX        41         /* 4G 模块 UART TX (ESP→4G)          */
#define PIN_4G_RX        42         /* 4G 模块 UART RX (4G→ESP)          */
#define PIN_4G_RESET     47         /* 4G 模块复位引脚 (低电平复位)      */

/* ====================================================================== */
/*   电源控制                                                             */
/* ====================================================================== */
#define PIN_PWR_3V8_EN   21         /* 3.8V 外部电源使能 (高电平开启)    */

/* ====================================================================== */
/*   ADC — 电池电压检测                                                   */
/* ====================================================================== */
#define PIN_BAT_ADC      11         /* 电池电压 ADC 输入 (ADC2_CH0)      */
#define PIN_BAT_MEAS_EN  39         /* 测量使能开关 (高电平时开启分压)   */

/* ====================================================================== */
/*   温度传感器                                                           */
/* ====================================================================== */
#define PIN_DS18B20      40         /* DS18B20 单总线数据引脚            */
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

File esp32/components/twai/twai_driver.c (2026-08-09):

/**
 * @file twai_driver.c
 * @brief TWAI (ESP32 内置 CAN) 驱动实现
 *
 * 封装 ESP-IDF 的 TWAI 驱动, 配置为 125kbps,
 * 提供安装/启动/停止/收发/Alert等待接口.
 *
 * Alert 中断:
 *   twai_read_alerts() 阻塞等待 RXI/DOI 硬件中断,
 *   无需轮询, 任务挂起至事件发生.
 */

#include "twai_driver.h"
#include "esp_log.h"
#include "driver/twai.h"
#include <string.h>

static const char *TAG = "TWAI";
static bool s_installed = false;        /* 驱动是否已安装标志 */
static bool s_alerts_configured = false; /* Alert 是否已配置    */

esp_err_t twai_driver_init(int tx_pin, int rx_pin)
{
    ESP_LOGI(TAG, "初始化 TWAI: TX=GPIO%d, RX=GPIO%d", tx_pin, rx_pin);

    /* 通用配置: 设置 TX/RX 引脚, 普通模式, 接收队列 128 帧 */
    twai_general_config_t g_config = TWAI_GENERAL_CONFIG_DEFAULT(
        (gpio_num_t)tx_pin, (gpio_num_t)rx_pin, TWAI_MODE_NORMAL);
    g_config.rx_queue_len = 128;

    /* 时序配置: 使用 ESP-IDF 内置的 125kbps 宏 */
    twai_timing_config_t t_config = TWAI_TIMING_CONFIG_125KBITS();

    /* 滤波配置: 接收所有帧 */
    twai_filter_config_t f_config = TWAI_FILTER_CONFIG_ACCEPT_ALL();

    esp_err_t ret = twai_driver_install(&g_config, &t_config, &f_config);
    if (ret == ESP_OK) {
        s_installed = true;
        ESP_LOGI(TAG, "TWAI 驱动安装成功 (125kbps)");
    } else {
        ESP_LOGE(TAG, "TWAI 驱动安装失败: %s", esp_err_to_name(ret));
    }
    return ret;
}

esp_err_t twai_driver_start(void)
{
    if (!s_installed) return ESP_ERR_INVALID_STATE;

    esp_err_t ret = twai_start();
    if (ret == ESP_OK) {
        /* 配置 Alert: 启用 RX 数据到达和 RX 队列满中断 */
        ret = twai_reconfigure_alerts(
            TWAI_ALERT_RX_DATA | TWAI_ALERT_RX_QUEUE_FULL, NULL);
        if (ret == ESP_OK) {
            s_alerts_configured = true;
            ESP_LOGI(TAG, "TWAI 通信启动, Alert 已配置 (RXI + DOI)");
        } else {
            ESP_LOGW(TAG, "Alert 配置失败: %s", esp_err_to_name(ret));
        }
    } else {
        ESP_LOGE(TAG, "TWAI 启动失败: %s", esp_err_to_name(ret));
    }
    return ret;
}

esp_err_t twai_driver_stop(void)
{
    if (!s_installed) return ESP_ERR_INVALID_STATE;
    s_alerts_configured = false;
    ESP_LOGI(TAG, "停止 TWAI 通信");
    return twai_stop();
}

void twai_driver_deinit(void)
{
    if (!s_installed) return;
    ESP_LOGI(TAG, "卸载 TWAI 驱动");
    twai_stop();
    twai_driver_uninstall();
    s_installed = false;
    s_alerts_configured = false;
}

esp_err_t twai_driver_transmit(const twai_frame_t *frame, uint32_t timeout_ms)
{
    /* 将自定义帧结构转换为 ESP-IDF 的 twai_message_t */
    twai_message_t msg = {
        .identifier = frame->id,
        .data_length_code = frame->dlc,
        .extd = frame->is_extended,
        .rtr = frame->is_rtr,
    };
    /* 复制数据 (排除远程帧, 远程帧无数据) */
    if (frame->dlc > 0 && frame->dlc <= 8 && !frame->is_rtr) {
        memcpy(msg.data, frame->data, frame->dlc);
    }

    esp_err_t ret = twai_transmit(&msg, pdMS_TO_TICKS(timeout_ms));
    if (ret != ESP_OK) {
        ESP_LOGW(TAG, "发送失败: %s", esp_err_to_name(ret));
    }
    return ret;
}

esp_err_t twai_driver_receive(twai_frame_t *frame, uint32_t timeout_ms)
{
    twai_message_t msg;
    esp_err_t ret = twai_receive(&msg, pdMS_TO_TICKS(timeout_ms));
    if (ret != ESP_OK) return ret;  /* 超时或无数据 */

    /* 将 ESP-IDF 消息转换为自定义帧结构 */
    frame->id = msg.identifier;
    frame->dlc = msg.data_length_code;
    frame->is_extended = msg.extd;
    frame->is_rtr = msg.rtr;

    /* 复制数据 */
    if (frame->dlc > 0 && frame->dlc <= 8 && !frame->is_rtr) {
        memcpy(frame->data, msg.data, frame->dlc);
    }

    /* 打印 TWAI 接收到的帧数据 */
    ESP_LOGI(TAG, "TWAI RX: ID=0x%03lX DLC=%d Data=%02X %02X %02X %02X %02X %02X %02X %02X%s%s",
             (unsigned long)frame->id, frame->dlc,
             frame->dlc >= 1 ? frame->data[0] : 0,
             frame->dlc >= 2 ? frame->data[1] : 0,
             frame->dlc >= 3 ? frame->data[2] : 0,
             frame->dlc >= 4 ? frame->data[3] : 0,
             frame->dlc >= 5 ? frame->data[4] : 0,
             frame->dlc >= 6 ? frame->data[5] : 0,
             frame->dlc >= 7 ? frame->data[6] : 0,
             frame->dlc >= 8 ? frame->data[7] : 0,
             frame->is_extended ? " EXT" : "",
             frame->is_rtr ? " RTR" : "");

    return ESP_OK;
}

bool twai_driver_wait_rx(uint32_t timeout_ms)
{
    if (!s_alerts_configured) return false;

    uint32_t alerts;
    TickType_t ticks = (timeout_ms == portMAX_DELAY) ?
                        portMAX_DELAY : pdMS_TO_TICKS(timeout_ms);

    esp_err_t ret = twai_read_alerts(&alerts, ticks);
    if (ret != ESP_OK) return false;

    if (alerts & TWAI_ALERT_RX_DATA) {
        return true;  /* RX FIFO 中有数据待读取 */
    }

    if (alerts & TWAI_ALERT_RX_QUEUE_FULL) {
        ESP_LOGW(TAG, "TWAI RX FIFO 溢出, 立即读取!");
        return true;  /* 溢出也需要读取 */
    }

    return false;
}

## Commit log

2026-08-09 Initial commit: ESP32-S3 multi-channel CAN data acquisition terminal
2026-08-13 feat(hardware): add OBD-CAN PCB design files (Gerber/BOM/schematic) under CERN-OHL-S-2.0
    [BOM_Board1_PCB1.xlsx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]
2026-08-13 chore(gitattributes): treat JLC Gerber manufacturing files as binary
2026-08-13 feat(hardware): add LCEDA Pro source project (.eprj2) and pick-and-place file
    [PickAndPlace_PCB1.xlsx]
